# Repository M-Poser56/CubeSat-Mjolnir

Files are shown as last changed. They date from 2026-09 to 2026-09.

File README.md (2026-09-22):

# CubeSat-Mjolnir
Repository for the Mjolnir CubeSat personal project, tracking all code and design material.

The Mjolnir CubeSat is a 10cm by 10cm by 10cm (1U) microsatellite complete with an onboard flight computer, sensor telemetry, radio module, a camera module, custom onboard BMS, onboard attitude control via reaction wheels and custom motor control PCB.

There is also a fully custom groundstation consisting of a python backend and JS frontend, meant to interface with an Arduino Uno running a script to interface with a matching LoRa radio module to the CubeSat.

Had a blast making this, design doc covers everything and is worth a read!

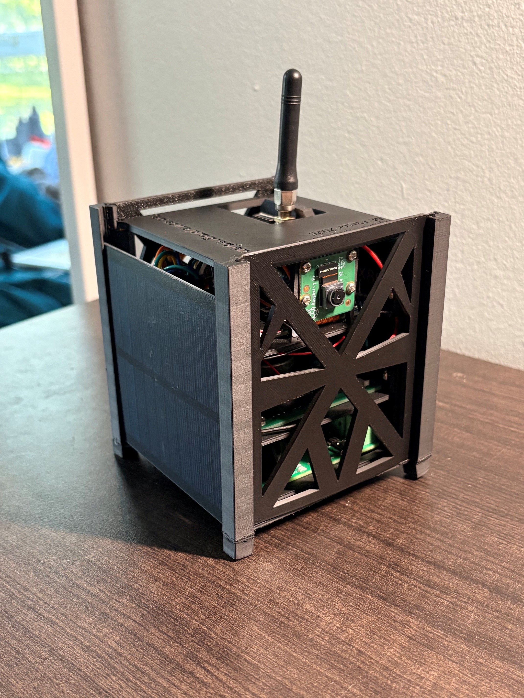
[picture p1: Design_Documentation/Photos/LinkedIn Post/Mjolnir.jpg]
Mjolnir CubeSat


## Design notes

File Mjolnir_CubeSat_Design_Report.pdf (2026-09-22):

# Mjolnir CubeSat Design & System Architecture Report

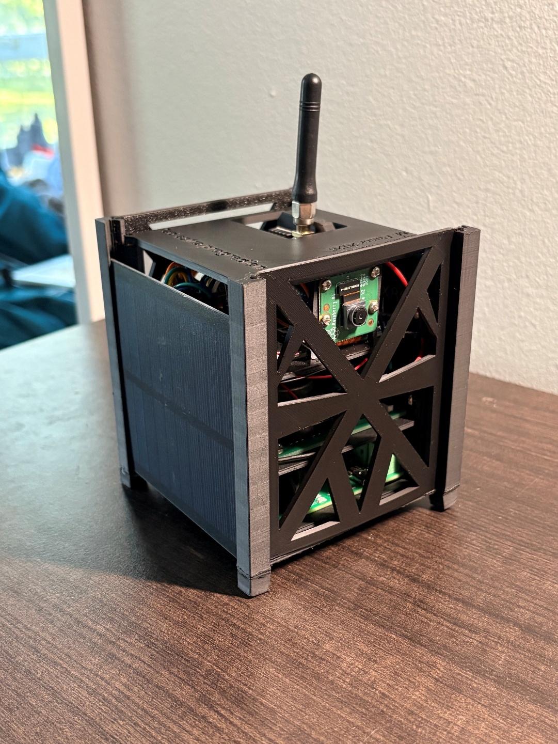
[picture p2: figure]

Matt Poser, Queen’s University Engineering Physics September 17th

, 2026

# Preamble/Abstract

The goal of this document is to notarize the design decisions, architecture, and detailed subsystems of the Mjolnir CubeSat personal project (similarly to my earlier M.A.E.S.T.R.O document) now that the Mk.I version is complete. This project was initially conceived when doing job market research and looking at the RocketLab Toronto engineering team, responsible for constructing reaction wheels and star tracker components for sale to the general space industry. Upon further research, I found out about student space projects, and specifically the CubeSat design standard used by industry engineers, hobbyists, and university students across the world. I set out to learn more and make my own, to learn about the relevant design challenges, subsystems and components commonly seen within the space industry and on operational satellites.
From a high level, the Mjolnir (Mk.I) CubeSat is a 1U design made from 3D printed PLA (fast prototyping), complete with an onboard Raspberry Pi Zero2W (flight computer), PiCamera V2, Adafruit LoRa radio module (915MHz), Adafruit BNO055 9 degree-of-freedom inertial measurement board, a custom made reaction wheel motor control PCB & reaction wheels, and a fully custom 5V output Lithium Ion (18650 cells) battery management system with a custom designed PCB. The CubeSat is specifically designed to communicate with a ‘ground station’ comprised of my laptop (running frontend display & backend software) paired with an Arduino Uno & accompanying Adafruit LoRa module which can receive onboard sensor telemetry, as well as send commands to change onboard configurations on the flight computer.
In its current state, the Mk.I is a simple prototype (and notably NOT spaceflight worthy), meant to act as a learning tool about PCB design, 3D modeling, software design, and relevant space applications. It works fully as intended, broadcasting down sensor telemetry packets and accepting commands from the ground station during active operation. Being a 1U design, there was not much room for scientific equipment or significant ‘launch payloads’, however if I ever were to attempt a 2U (or larger) footprint CubeSat I would attempt this, and possibly make it launch-worthy. I had an absolute blast with this project, and I am hoping to use it as a talking point in interviews and on job applications (if you’re a recruiter reading this, get in touch!). I set out on this project to learn, and to improve my skills in 3D modeling, software, and PCB design, and achieved all of those goals in full.
- Matt Poser, Sept. 17th 2026

## Table of Contents

Mjolnir CubeSat Design & | 1
System Architecture Report | 1
Preamble/Abstract | 2
Project Motivation, Background | 5
Initial LoRa Radio Test | 8
General System Architecture, Operation | 10
Mechanical Design, Tray System | 12
Tray I – BMS & Power Supply Board | 15
Tray II – Reaction Wheels | 20
Tray III – Flight Computer, IMU, Radio, Startracker | 24
Flight Computer Software | 27
Groundstation, Software & Hardware | 29
Final Assembly, Future Project Considerations | 30

Figure 1- Star Trackers, from the RocketLab Website: https://rocketlabcorp.com/space-
systems/satellite-components/star-trackers/ | 5
Figure 2- Reaction wheels, from the RocketLab website: https://rocketlabcorp.com/space-
systems/satellite-components/reaction-wheels/ | 6
Figure 3- 1U CubeSat footprint design standard, CubeSat official foundation | 7
Figure 4- Adafruit LoRa modules, selected to be used both onboard the CubeSat and on the
groundstation | 8
Figure 5- Soldering job of the two purchased Adafruit radio modules. Note the safety goggles on the
left, PPE is important! | 9
Figure 6- Photo of the 'test bench' setup for the LoRa radio hardware test. See the 'groundstation'
Arduino on the left hand side, and the Pi 4B on the right hand side | 9
Figure 7- Note the shell output from the Pi side of the ping pong script. Messages were actively being exchanged back and forth between the two radios, on regular intervals, for sustained periods
of time | 10
Figure 8- Initial CubeSat tower design. Struts and flat base follow 1U design standard | 12
Figure 9- Model for CubeSat frame with risers and machined holes for heat set inserts | 13
Figure 10- Heat set inserts installed in the Mk.I outer frame | 13
Figure 11- CubeSat outer frame with teal tray template prints installed at various heights within the CubeSat. These were used to confirm design dimension, as well as verify fit and the ideas behind
the tiered system | 14
Figure 12- used a Dremel tool to file down the slots of the CubeSat in an attempt to fit the solar panels. The height dimension was correct, however in the end the frame required a redesign of the
slots in order to accommodate the solar panels as wall units | 14

Figure 13- CubeSat Lid, the last component to be designed for the structural system and the

Figure 23- Motor control PCB circuit, using two of the Texas Instruments L293DNE ICs. Two dual H bridges meant 4 total motors could be controlled, but I only required 3 axes of control, thus one

Figure 26- Motor control PCB soldered, and fastened to reaction wheel tray along with reaction wheel motors. Flywheels would be printed and assembled later, along with all wiring connections

Figure 27- basic layout of Adafruit BNO055 IMU board, Mjolnir flight computer, LoRa radio module

Figure 32- IMU sub-script, interfaces with Adafruit IMU to obtain attitude and temperature readings, publishes sensor packet to an mqtt topic read by the main LoRa script, which is then sent down to

Figure 34- Arduino Uno groundstation module. Yellow serial cable plugs into the USB port of my

Figure 35- Initial electronics test. See the mess of wires coming out of the flight computer, the 3D printed flywheels on the reaction wheel motor controller, and the bench power supply being used

# Project Motivation, Background

As I mentioned in the executive summary portion of this document, I had initially been looking into jobs for various internship roles while at Queen’s & on my internship at OPG. I had found a posting for RocketLab’s engineering team which worked on making reaction wheels and star trackers for satellite applications, and at the time I had yet to learn what either of these were. Intrigued, I did some research and found documentation both star trackers and reaction wheels, as well as their use in spacecraft design. For the un-initiated, a star tracker is a special kind of camera which takes photos of the stars while a spacecraft is in orbit or traveling through space. The star tracker then maps this photo to a known star map (360* panoramic view of the night sky), using specially designed software to determine the vector direction that the camera (and thus spacecraft) is pointing in, as well as the angular orientation. This is an important task for navigation of spacecraft, as well as calibrating the onboard orientation sensors to a known source.

Figure 1- Star Trackers, from the RocketLab Website: https://rocketlabcorp.com/space-systems/satellite-components/star-trackers/ (https://rocketlabcorp.com/space-systems/satellite-components/star-trackers/)
The next component I had yet to learn about was reaction wheels. Once your spacecraft has its exact angular orientation in space determined (combination of star tracker & onboard sensors), the operators back on earth (or onboard) may wish to change the angular orientation. This could be to face solar panels towards the sun, change attitude (angular orientation) to face a celestial body/source for imaging, or other reasons. You could accomplish this with thrusters, however reaction wheels also achieve the task of changing angular orientation in space, via the conservation of angular momentum. Let’s frame the problem as the following. Your spacecraft has a total moment of inertia Ispacecraft. If we define the total angular momentum of the spacecraft as Lspacecraft, we can represent it with the following equation:
Lspacecraft = Ispacecraft ∗ ω | (1)
Where ω is the angular momentum of the entire spacecraft body, with all of its components. We will say, that buy and large after launch, our spacecraft is rotating a minimal amount in a nearby observer’s frame of reference. Thus, Lspacecraftis equal to 0. Since we know that Ispacecraft is nonzero (our spacecraft has mass), then we know that our spacecraft’s total angular momentum (ω) must be 0. Thus, our equation (1) becomes:

0 = Ispacecraft ∗ ω
Now, what we will do is break up the above equation into a combination of simple parts. We can say that the total angular momentum of our spacecraft, is equal to the sum of the angular momentum of smaller components within the spacecraft, along with the spacecraft’s outer body. For now, we will formalize this along one arbitrary axis, saying we have a single internal component which can take angular momentum ω2. Our equation (1) then becomes:
0 = Ibody ∗ ω1 + Iflywℎeel ∗ ω2 | (2)
We can see, that for the above equation to remain valid, either ω2 = ω2 = 0, or they must take opposite signs and cancel one another out, as we specify that both Ibody and Iflywℎeel are positive real tensors (though, in this single axis approximation we can think of them as scalar values). What this means is that if there is no external addition of angular momentum to the entire spacecraft assembly, you can still induce angular momentum in the external spacecraft body by making an internal component spin (have nonzero angular momentum). This in turn allows the crew to rotate the spacecraft, altering its attitude in a known and controlled way. This internal rotating component used to change spacecraft attitude, is the reaction wheel. Perhaps an easier (and less long winded) way to think about this is to say that if our spacecraft starts at rest (no angular momentum), and a wheel inside starts spinning in one direction, the whole spacecraft (external body) must rotate in the other direction to conserve angular momentum, which remains zero for the entire spacecraft.

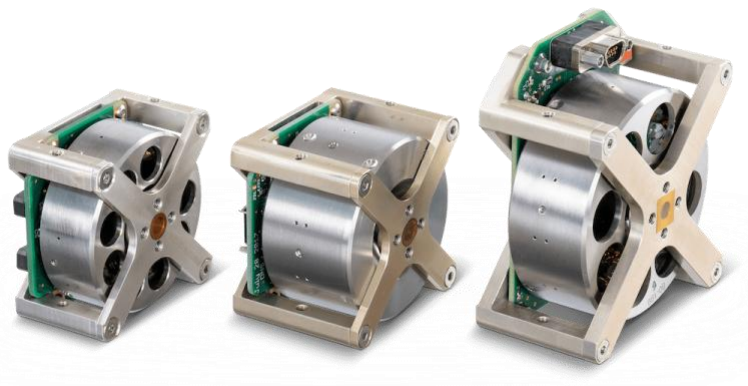
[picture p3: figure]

Figure 2- Reaction wheels, from the RocketLab website: https://rocketlabcorp.com/space-systems/satellite-components/reaction-wheels/ (https://rocketlabcorp.com/space-systems/satellite-components/reaction-wheels/)

Having learned about all of this, I was now curious about the industry of satellite design. I also found several resources pointing to CubeSats; used for both real-world space deployments and by university teams. CubeSats (as I have come to know) are satellites which follow a specific design standard, limiting their total physical footprint to multiples of 10cm/10cm/10cm. A singular 1000cm³ satellite is referred to as a 1U (1 unit) CubeSat, and different multiples of this are referred to aptly as 2U, 3U, so on and so forth up to 12U satellites. Shown below is a photo of the official 1U design standard from the CubeSat foundation:

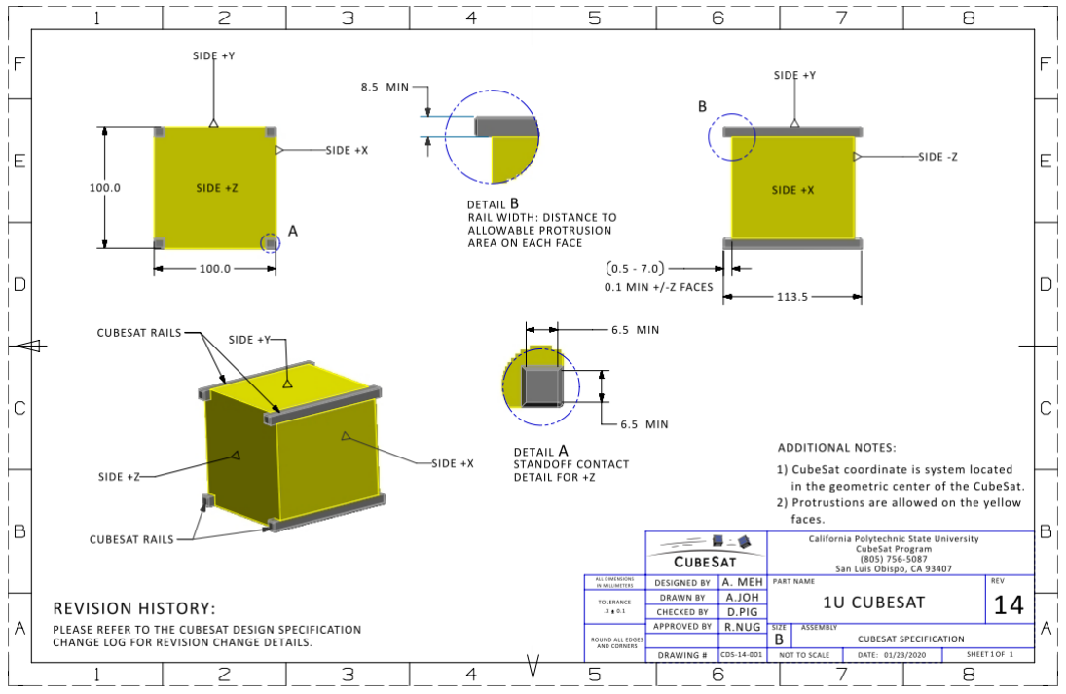
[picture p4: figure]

Figure 3- 1U CubeSat footprint design standard, CubeSat official foundation
The best thing about CubeSats for both students and professionals is that they were invented to circumvent the costs of launching satellites into orbit. Before CubeSats, launching a satellite meant that an organization would spend potentially millions of dollars building and launching a behemoth sized instrument on a rocket. This made the practice of satellite design and operation inaccessible at an entry level. With the much smaller footprint CubeSats, engineers and physicists can collaborate to design satellites for scientific purposes on a smaller scale for reduced cost and can afford to launch via rideshare. Instead of a company paying 6 (or more) figures to use a dedicated launch vehicle to put only their satellite into orbit, rideshares via companies like NASA or SpaceX will carry and launch hundreds of these CubeSats at a time on a single launch vehicle, allowing participating parties to collectively pay for the launch vehicle operation & reduce the cost of putting their experiment in space.
By this point I was thoroughly intrigued, and wanted to take on the project of building my own CubeSat (despite not being able to afford the roughly $50,000 - $80,000 rideshare launch bill). I began project planning for a 1U CubeSat of my own, and made a laundry list of technical skills I hoped to practice and improve upon during this project. In late April 2026, I kicked off the project and began documentation.

# Initial LoRa Radio Test

Similarly to my M.A.E.S.T.R.O desktop robotic arm project (also on my GitHub, check it out!), this project too relied on a core concept/component, and without proper operation/functionality the project would not be able to be attempted. For this project, that concept was radio communication via an I/O module, in this case a LoRa radio module. LoRa radio simply stands for long range radio, and is a special standard of radio communication which is used to send signals & information from node to node. LoRa radios are considered useful for simple & low power radio applications (with surprisingly good range), and can be configured in networks and meshes for message relaying. In this application, my understanding was that my CubeSat (Mjolnir, Mk.I) would require an onboard radio module which could both send and receive messages/packets. This onboard radio would need to communicate with a groundstation of some kind, built to receive onboard information from the CubeSat and also send commands to the onboard flight computer. I planned outright to use a Raspberry Pi Zero 2W running headless Linux as my flight computer, making use of the GPIO pins and python as a powerful I/O base for onboard sensors & modules. Using this as initial inspiration, I settled on the Adafruit RFM9x 915MHx LoRa modules. These modules were relatively low power and used GPIO based SPI (serial peripheral interface) communication protocol to operate. Further, there was a supported software library for both the python operated GPIO on the raspberry Pi (Adafruit custom), as well as the Arduino microcontroller family (radiohead library). The choice of an Arduino (Uno) is discussed later in the groundstation section of the report, but ultimately the flight computer radio module was to be operated by the onboard Raspberry Pi Zero 2W flight computer & python, while the groundstation would use the Uno & radiohead.

Figure 4- Adafruit LoRa modules, selected to be used both onboard the CubeSat and on the groundstation
When purchased and delivered, the antennae had to be soldered onto both boards, using a special SMD (surface mounted device) for antenna connection. This was my first experience doing non through-hole soldering, and took a lot of patience to complete. Eventually, I was able to finish the job & assemble both radio boards for use:

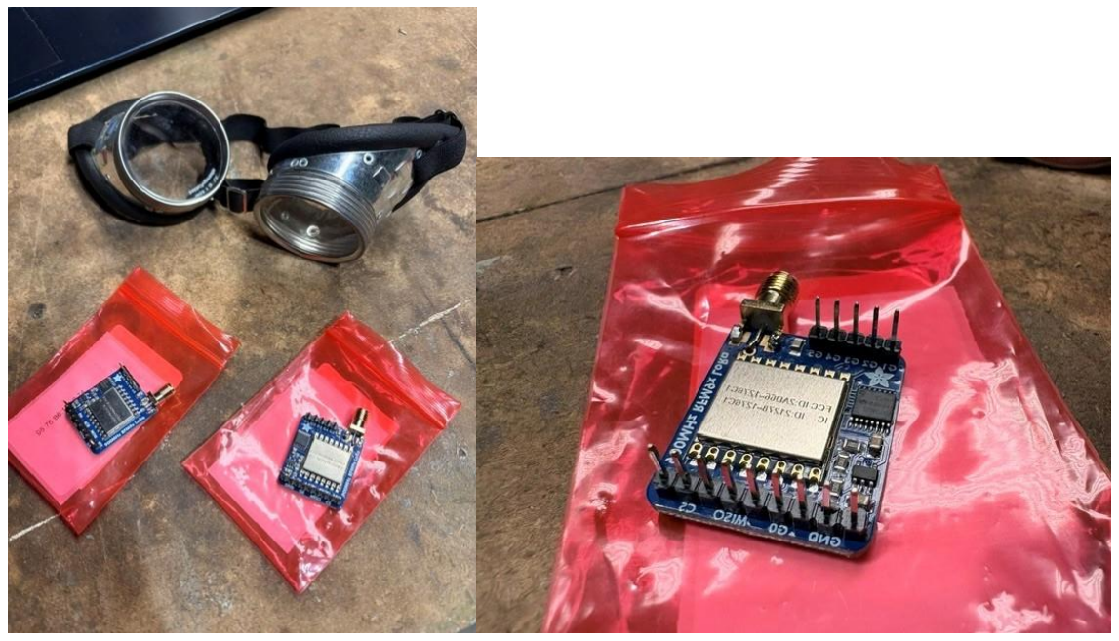
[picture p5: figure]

Figure 5- Soldering job of the two purchased Adafruit radio modules. Note the safety goggles on the left, PPE is important!
Once finished with the soldering job, I wrote up a quick ‘ping pong’ script for both the Arduino, and a Raspberry Pi 4B (nice to develop on a desktop environment, while still using python/GPIO the same way as the Zero 2W would), where one radio would send out a ping, and wait for the other radio to respond with a ‘pong’ return message. Once wired up on both the Pi 4B and Arduino Uno, the test ran successfully verifying that these LoRa modules could be used, as well as the fact that my soldering job held up (which, in and of itself, was no small act of divine intervention).

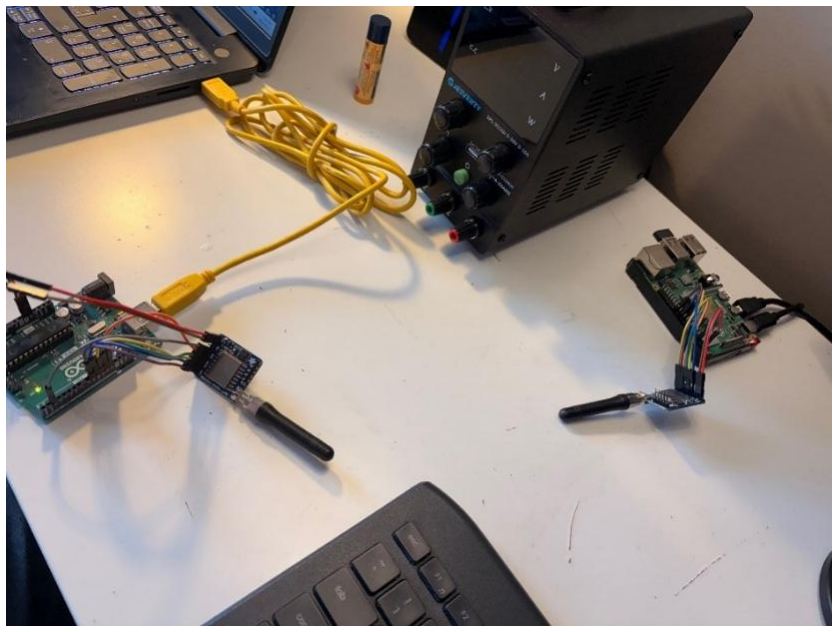
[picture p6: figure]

Figure 6- Photo of the 'test bench' setup for the LoRa radio hardware test. See the 'groundstation' Arduino on the left hand side, and the Pi 4B on the right hand side

Figure 7- Note the shell output from the Pi side of the ping pong script. Messages were actively being exchanged back and forth between the two radios, on regular intervals, for sustained periods of time
With this successful test, the project could now be fully attempted. If the radio modules did not end up working, then alternative options would have been explored until a viable choice was found for the project. However, this easy use case meant that I could proceed with a general architecture of CubeSat and groundstation in mind.

# General System Architecture, Operation

The general architecture of the CubeSat project is that of an uplink/downlink communication scheme. Under regular operation, I wanted the CubeSat to publish regular packets down to the groundstation, alongside other system/operational information as needed. The groundstation would display this information to the operator via a nice frontend display panel, which doubled as an interactive and easy to use control station to send commands to the CubeSat. Onboard the CubeSat, I would need to mesh onboard instruments such as the LoRa radio module, reaction wheels, star tracker camera, and inertial measurement sensor (angular orientation/attitude measurements, temperature) with the Pi Zero2W flight computer. The flight computer would dually need to send packets down in a known protocol to be processed by the ground station, as well as receive and process known commands coming from the ground station to perform preset flight computer operations. Below is the block diagram format of both the groundstation & CubeSat high level architecture:

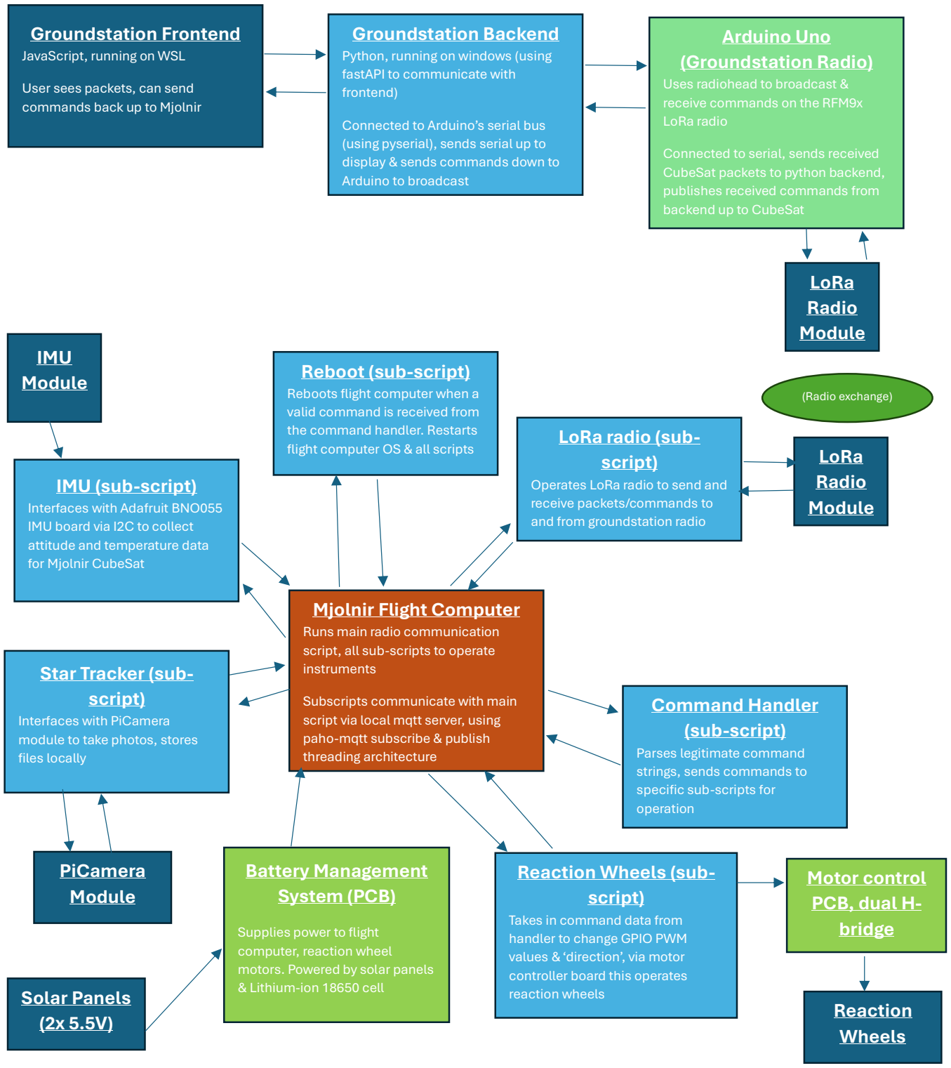
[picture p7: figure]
Groundstation Frontend JavaScript, running on WSL; User sees packets, can send commands back up to Mjolnir; Groundstation Backend Python, running on windows (using fastAPI to communicate with frontend); Connected to Arduino’s serial bus (using pyserial), sends serial up to display & sends commands down to Arduino to broadcast; Arduino Uno (Groundstation Radio) Uses radiohead to broadcast & receive commands on the RFM9x LoRa radio; Connected to serial, sends received CubeSat packets to python backend, publishes received commands from backend up to CubeSat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

# Mechanical Design, Tray System

The work for this project began with the design of the physical enclosure to hold all components within the CubeSat. At this point, I had brainstormed general components which would be included in the CubeSat’s design, however I did not have a concrete idea as to how I should mount and fasten them when inside the frame. I had the idea that the physical enclosure should follow a ‘tower’ design, with mounting points along vertical struts for components to be screwed in. I designed the tower to dimension with the 1U standard, and was able to produce the following initial 3D model:

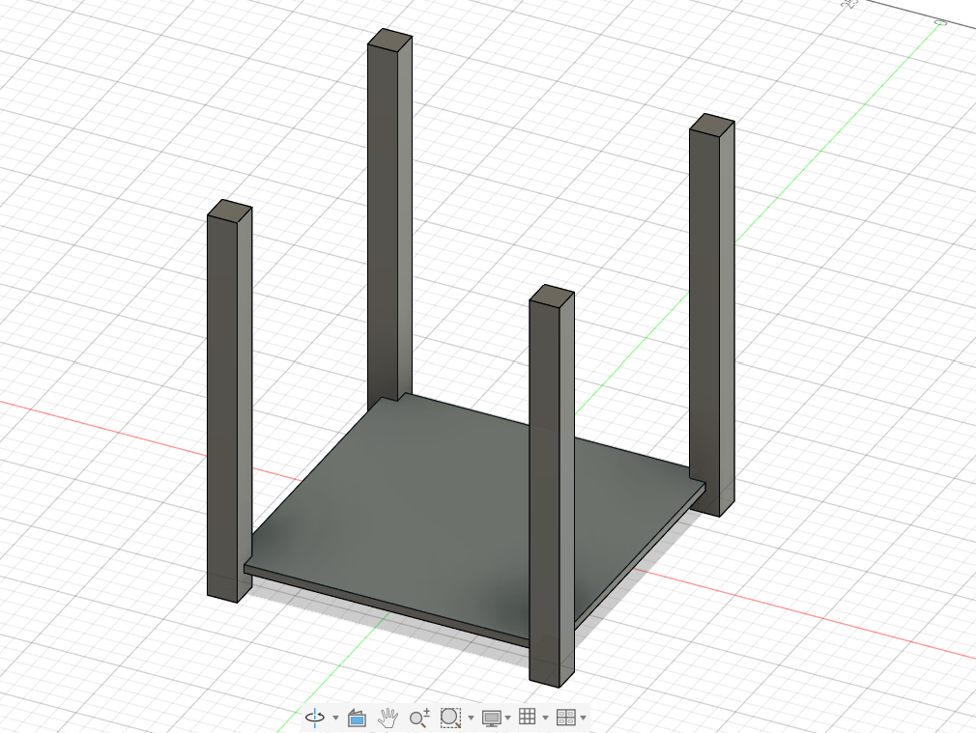
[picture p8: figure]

Figure 8- Initial CubeSat tower design. Struts and flat base follow 1U design standard
To mount objects to these towers, I designed in further risers which would hold heat set inserts. Planning on 3D printing these prototypes for this project, heat set inserts allowed me to have a way to use metric fasteners (M3 for this project) to mount all of my components to the frame. Heat set inserts are used by machining a pre-drilled hole in a 3D print, and with a soldering iron pressing in the inserts (heat melts away the plastic around them) to hold them securely in place. This provides a secure threaded anchor for M3 screws. Photos are shown below of the frame’s 3D model, and the heat set inserts assembled into the mounting points.

Figure 9- Model for CubeSat frame with risers and machined holes for heat set inserts

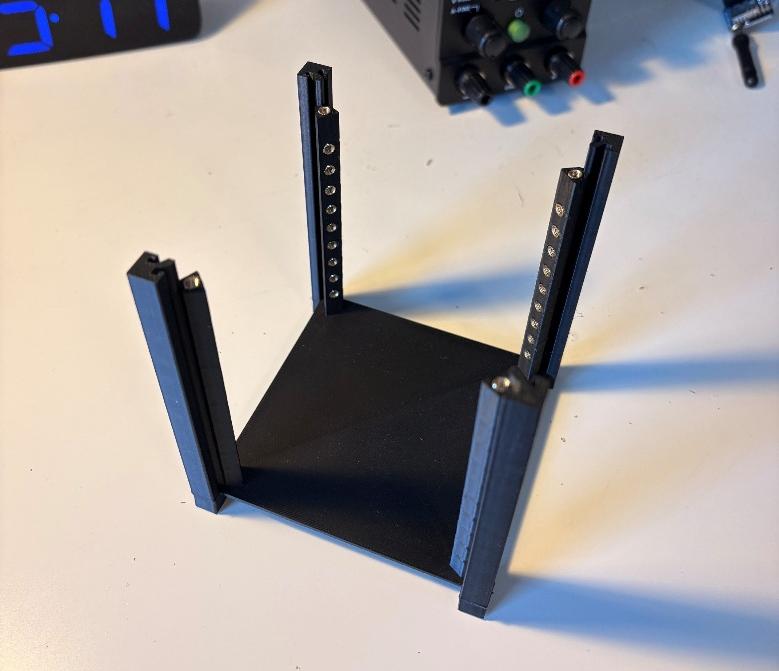
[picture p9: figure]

Figure 10- Heat set inserts installed in the Mk.I outer frame
In the designing of these towers, I also elected to implement slots for future installations of walls, as at the moment I did not know what they would look like exactly. Zooming in on the top of the tower in figure 10 shows this, there are acceptor slots which would allow a general wall design to be slid in from the top and held in place by a lid.

After the installation of the heat set inserts on the first frame, I had the idea of implementing a tiered ‘tray’ design. If I had a general footprint for a platform which could be fastened into the heat set inserts via M3 screw, I could start with the same template sketch for all trays which I wanted to install in the CubeSat. This also made it a modular design, meaning in theory trays could be swapped in and out and installed in different configurations. Shown below are some photos taken later in the CubeSat’s design phase, including the teal-colored tray template prints fastened to the frame design, as well as the purchased solar panels inserted into machined slots in the frame (solar panels were big enough to act as the CubeSat walls).

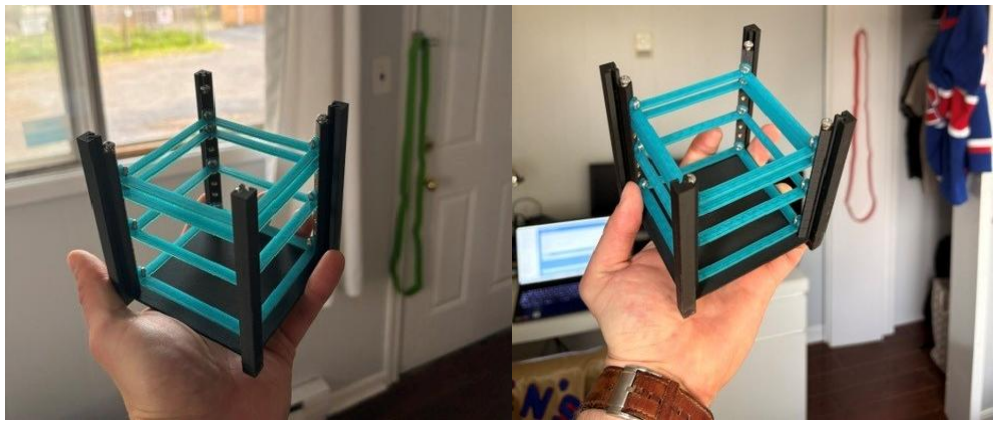
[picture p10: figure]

Figure 11- CubeSat outer frame with teal tray template prints installed at various heights within the CubeSat. These were used to confirm design dimension, as well as verify fit and the ideas behind the tiered system

Figure 12- used a Dremel tool to file down the slots of the CubeSat in an attempt to fit the solar panels. The height dimension was correct, however in the end the frame required a redesign of the slots in order to accommodate the solar panels as wall units

The structural subsystem was the least intensive part of this project, and was also the first component to undergo design work (the frame), as well as the last (the lid). A photo of the final CubeSat Lid 3D model is shown below, this lid screws into the top of the frame towers to cap off the top tray (containing flight computer, IMU, radio, and camera module).

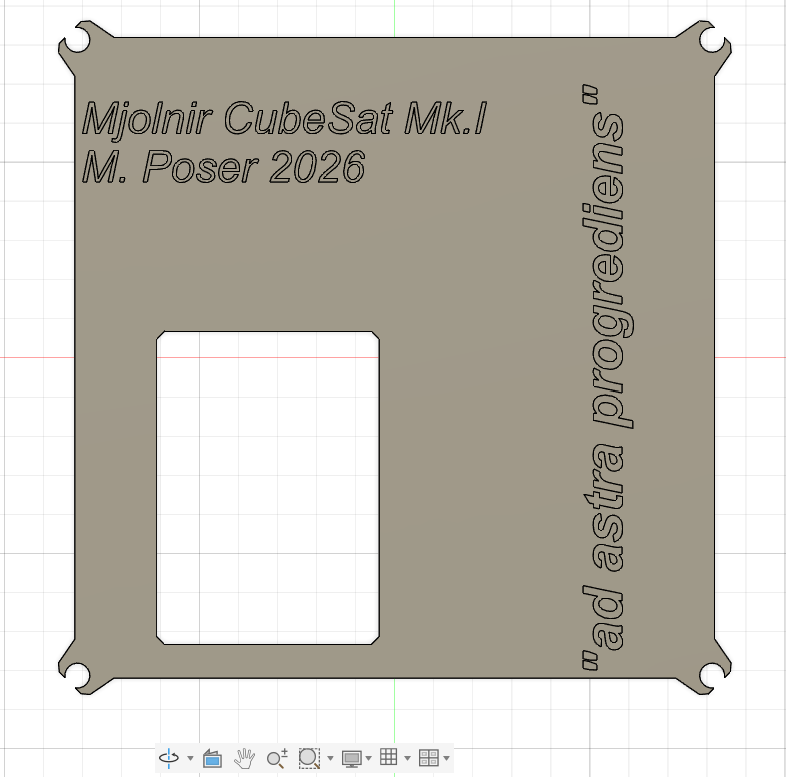
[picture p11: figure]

Figure 13- CubeSat Lid, the last component to be designed for the structural system and the CubeSat as a whole. Latin saying roughly translates to "forward unto the stars"

# Tray I – BMS & Power Supply Board

The BMS (battery management system) for this CubeSat was an immense amount of work, and presented a very large learning curve for me in terms of PCB design. When talking about this project with one of the engineers on my team at OPG, he convinced me to try and make a custom made BMS, as opposed to purchasing a basic one off the market (my initial inclination). He recommended that I begin with chip design, and lay out a couple of key functionalities for the board:
1. Board must be powered by an 18650 Lithium ion cell, 3.7V nominal
2. Board must have power path management, take in power from both the battery source and the solar panel charging units
3. Board must have aforementioned 18650 cell protection (undervoltage, overvoltage, overcurrent, temperature)
4. Board must take the varying output voltage from the battery/solar panels and boost it up to a consistent 5V
For these basic specifications, I selected the TI-BQ24074 charging chip, TI-BQ29704 battery protection chip, and the TPS61023 boost converter chip for power output. I essentially followed the exact sample designs from the Texas Instruments design manuals for each chip, stringing each chip together in the schematic to complete the design. I also elected to include a USB-C power input on my BMS PCB, considering that much of the testing I would be conducting would occur at my desk, and I had a high current desk power supply on hand for quick battery charging. Screenshots of each major component/circuit are shown below, with KiCAD comments outlining the specific function of each circuit on the board:

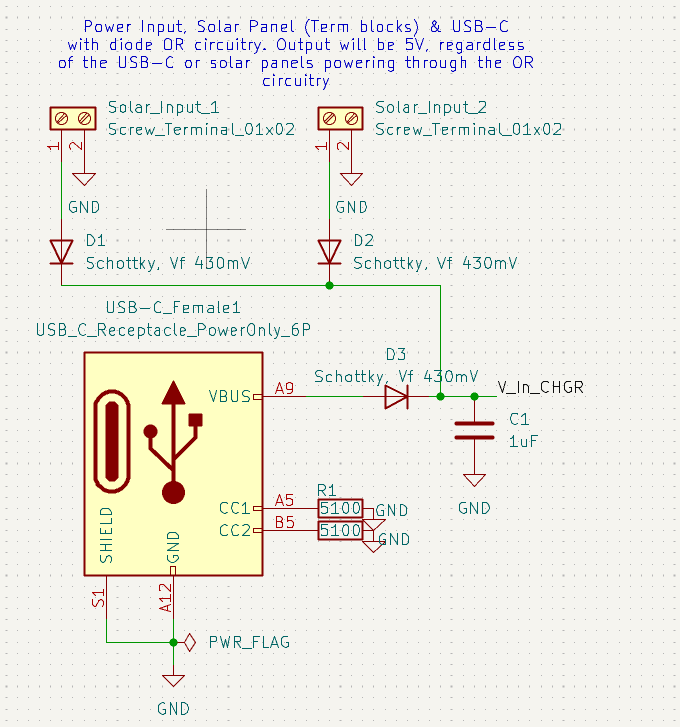
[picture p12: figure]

Figure 14- Power input circuit, with diode OR circuit to feed charging chip

Figure 15- Power path charging chip circuit

Figure 16- Battery protection circuit

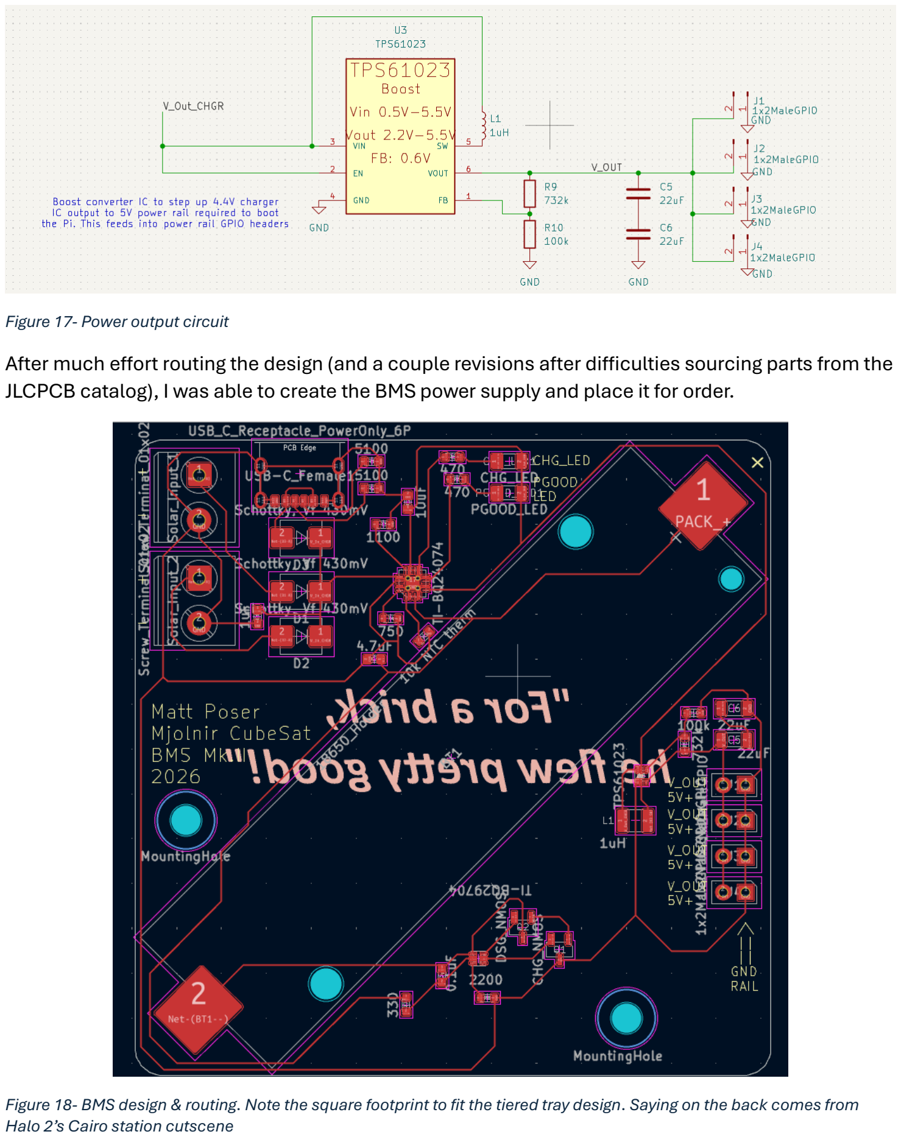
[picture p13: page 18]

Figure 17- Power output circuit
After much effort routing the design (and a couple revisions after difficulties sourcing parts from the JLCPCB catalog), I was able to create the BMS power supply and place it for order.

Figure 18- BMS design & routing. Note the square footprint to fit the tiered tray design. Saying on the back comes from Halo 2’s Cairo station cutscene

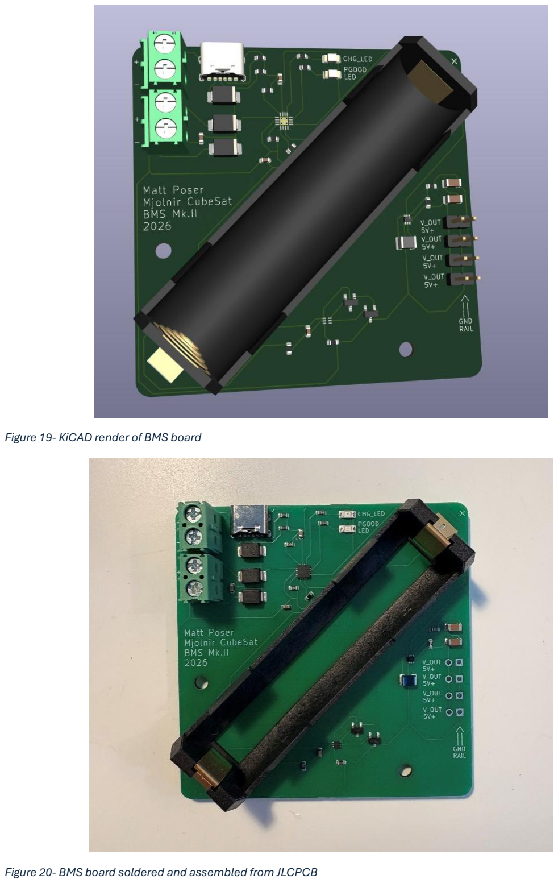
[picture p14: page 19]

Figure 19- KiCAD render of BMS board

Figure 20- BMS board soldered and assembled from JLCPCB

Figure 21- BMS Power test
By far, out of all aspects of this CubeSat project, I struggled the most with the PCB design for the BMS. It was amazing to see it all come together after weeks and weeks of effort, and to finally see the green light turn on during testing was a really awesome sight. This struggling with KiCAD and JLCPCB also prepared me greatly for the much easier reaction wheel motor control PCB design, so much so that I was able to knock out the motor control PCB in one sitting, and have the order placed with JLCPCB within one afternoon.

# Tray II – Reaction Wheels

As I discussed in the introductory section of this report, one of the main inspirations for this project was the reaction wheel subsystems seen on satellites and other spacecraft. My 1D approximation of the conservation of angular momentum problem would now be applied along three axes, to control pitch, roll, and yaw of the CubeSat. The first part of this component which needed to be selected was the reaction wheel motors themselves. I was operating under some serious engineering constraints, left with only a 5V power supply and limited space for 3 flywheel motors my options were limited. I settled with a cheap option from amazon, a basic cylindrical 5V DC motor with high enough rpm (roughly 1000) to spin the reaction wheels fast, while maintaining a small footprint within the constrained space of my 1U design.

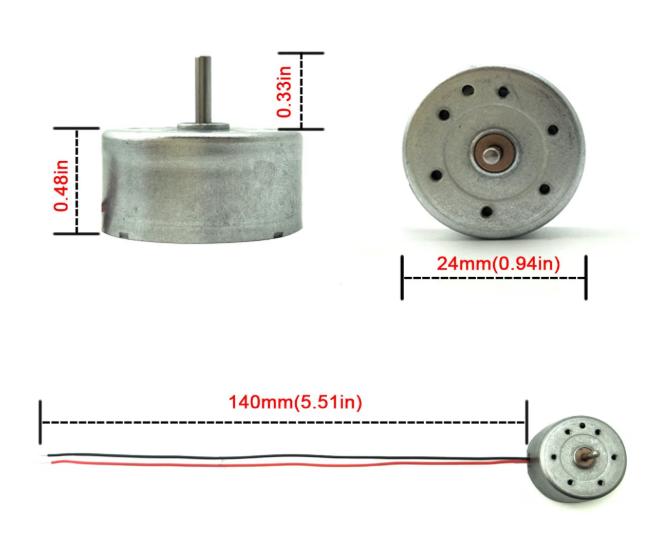
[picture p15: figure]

Figure 22- 5V DC motors off amazon
Luckily, I had experience using H-bridge motor control chips before, from my time spent tinkering with an Arduino starter kit in my first year at Queen’s. In the starter kit, there was a Texas instruments L293DNE dual H-bridge motor IC, with built in flyback diodes (designed specifically for use with DC motors). This chip operates by using a series of input pins, to control the motor using low-current logic PWM pins (for speed) and low current digital pins (for direction). It has a separate power bus for the motors, so your logic pins are never electrically connected to your motor and thus would not cause damage to the controller (in this case, the logic pins coming directly from the Mjolnir’s flight computer). I built a quick test circuit to ensure that the L293DNE was 3.3V logic compatible (Raspberry Pi has 3.3V GPIO I/O & PWM) and began work designing the motor control PCB.

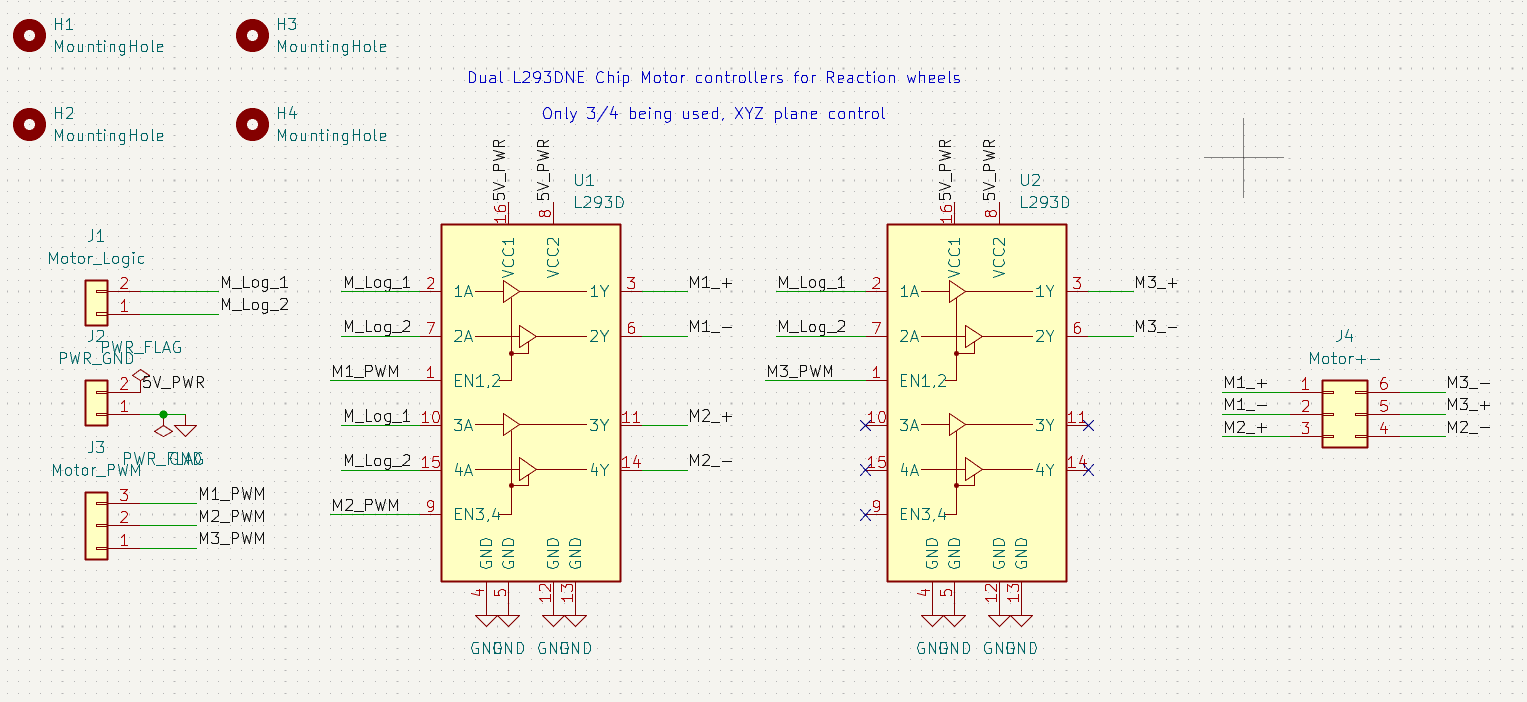
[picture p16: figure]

Figure 23- Motor control PCB circuit, using two of the Texas Instruments L293DNE ICs. Two dual H bridges meant 4 total motors could be controlled, but I only required 3 axes of control, thus one was left empty

The above circuit takes in two digital logic pins (0,1 or 1,0) which determines the direction of all motors in the circuit (clockwise versus counterclockwise). The 3 PWM pins on the above circuit receive 3.3V PWM signals of varying duty cycles (set to 490Hz) from the Mjolnir flight computer, and are used to control motor speed on each of the pitch/roll/yaw motors. The choice of 490Hz was made to mirror my past (and well tested) use of these TI chips with an Arduino Uno’s PWM outputs, which are set to 490Hz for standard pins. Under normal operation the Mjolnir flight computer would be receiving commands from the groundstation to set the states (direction, speed) of the pitch/roll/yaw motors, which would subsequently be outputted to these pins on the motor control board to interface with the reaction wheel motors. The circuit was traced out for the above PCB, and all the soldering for these boards was completed by me as opposed to the BMS which was assembled by JLCPCB.

Figure 24- motor control traces. Also experimented with more PCB layers for drawing traces

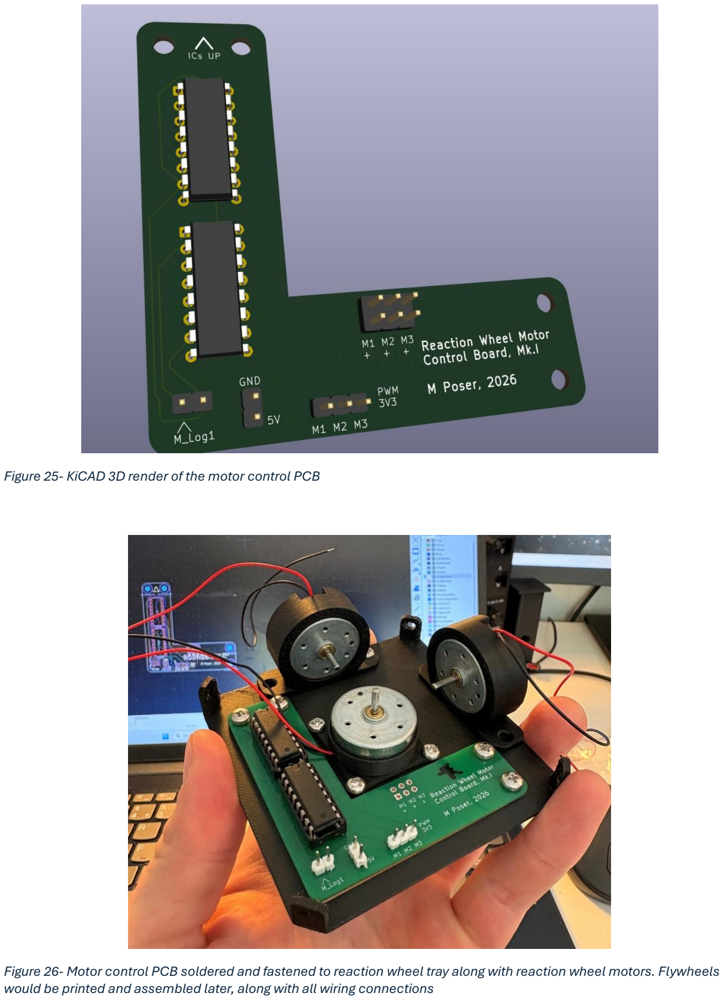
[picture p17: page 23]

Figure 25- KiCAD 3D render of the motor control PCB

Figure 26- Motor control PCB soldered and fastened to reaction wheel tray along with reaction wheel motors. Flywheels would be printed and assembled later, along with all wiring connections

Contrary to the BMS PCB design, I had a lot of fun making this motor control PCB, and of all the trays on the CubeSat this one is by far the cleanest and the nicest organized. This board underwent basic testing before final soldering and assembly, and performed admirably. The 5V motors also (surprisingly so) pulled much less current than expected at full draw, meaning there was not much strain on the BMS power supply even while running alongside the flight computer & radio module in active operation.

# Tray III – Flight Computer, IMU, Radio, Startracker

This final tray on the CubeSat contained much of the finer components in the design, and can be seen as the ‘brain’ of the Mjolnir CubeSat. This final tray would contain the central flight computer, radio module, inertial measurement unit, and (after iteration) the camera module. As well, for the sake of the radio antenna sticking out of the top of the CubeSat, this tray would be mounted at the top. Before completing any major wiring, a basic layout of the top tray was printed and assembled, to assess space constraints.

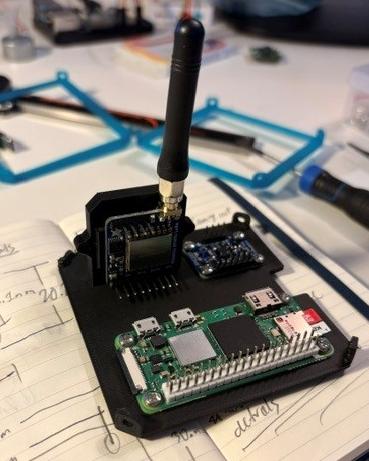
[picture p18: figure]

Figure 27- basic layout of Adafruit BNO055 IMU board, Mjolnir flight computer, LoRa radio module

Figure 28- top tray assembled on frame with BMS

Figure 29- Top tray assembled on frame with BMS (2)

Once this basic orientation was figured out, the next component to be added was the PiCamera module for the star tracker. Based on the length of the available camera cable with the module, this also was chosen to be mounted and included in this top tray. Shown below is the 3D model of the top tray, with the outwards facing mount for the PiCamera module. It was noted here that the wall design on this side of the CubeSat would need to have a hole/opening in its face to accommodate the camera’s field of view facing outwards.

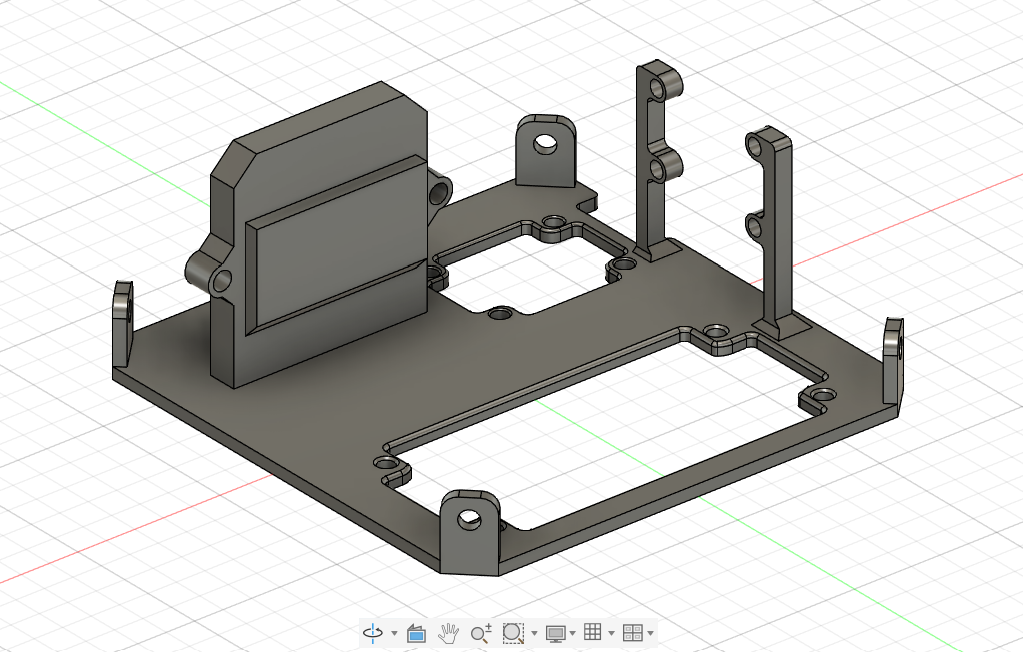
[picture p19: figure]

Figure 30- Top tray with PiCamera mounting arms extruded from the base of the tray
It is pertinent to note that this tray was impossibly hard to print, the small thin arm extrusions for the PiCamera were very finnicky, and often broke either in printing or in assembly afterwards when fastening the camera on. Eventually, all components were mounted on the tray, and I began initial testing of the flight computer software. Shown below is a photo of the top tray with some of its initial wiring completed (IMU & reaction wheel controls still disconnected from flight computer).

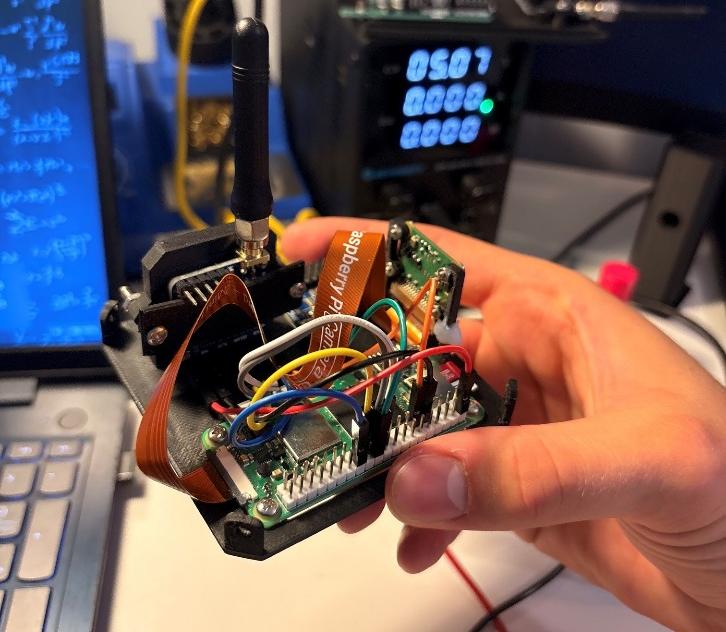
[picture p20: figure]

Figure 31- top tray assembled with PiCamera and LoRa radio module

# Flight Computer Software

The software on the flight computer was very fun to write, and served as the culmination of the project (alongside the software & hardware of the groundstation, next section). As shown in the above general architecture section, the software on the flight computer is all written in python as a series of sub-scripts which communicate with one another using mqtt architecture (mqtt-paho python library). This mqtt architecture was something I had the opportunity to learn about while on my co-op placement at OPG, and is definitely one of the cooler items in my software ‘bag of tricks’. Each script revolves around the same general architecture:
1. Check for a message on an incoming mqtt topic which the script is subscribed to
2. Do something with that packet/message
3. Once the function has been run either publish a message to another topic or report success
4. Continue loop
While unfortunately I do not have the page count in this report to explain the architecture of mqtt at length, the long and short of it is that it is a way for different python scripts running completely separately from one another to exchange information in an asynchronous fashion using built in functions in the paho-mqtt package. The flight computer sets up a local mqtt server/broker, and paho-mqtt allows scripts to publish and read packages from specific ‘topics’ (like directories) within this local server in a totally asynchronous fashion. What this looks like for the flight computer is that I can have a radio script running which receives IMU (inertial measurement unit) data via a separate script interfacing with my Adafruit IMU and publishing the sensor packets to a specific IMU/PACKET topic. Meanwhile, that same script can publish command data received from its radio to a COMMAND/ topic, which is then received by the command handler script running on a separate python instance. The flow of this controlled madness is outlined in the general architecture section’s block diagram, and with some reading of the code on the GitHub can be well understood. I tried to write the flight computer code with minimal usage of AI, and thus in some places it looks clunky. While it can be improved, I am happy because it is original code which runs without error. Shown below is a snippet of code, the IMU controller script which publishes IMU data to a topic read by the main LoRa radio control script.

Figure 32- IMU sub-script, interfaces with Adafruit IMU to obtain attitude and temperature readings, publishes sensor packet to an mqtt topic read by the main LoRa script, which is then sent down to the groundstation as a sensor packet

# Groundstation, Software & Hardware

Unlike the software written for the flight computer, I had a (relative) distaste for frontend design, and largely used AI to ‘vibecode’ this frontend portion of the project. As I mentioned earlier in this report, what I hoped was that the groundstation would be like an operator’s interface; allowing for the fast visualization of the sensor telemetry coming from the CubeSat, as well as providing the operator with a command panel and preset commands to broadcast to the CubeSat to perform onboard functions. The final command panel frontend is shown below, and the feature list discussed afterwards:

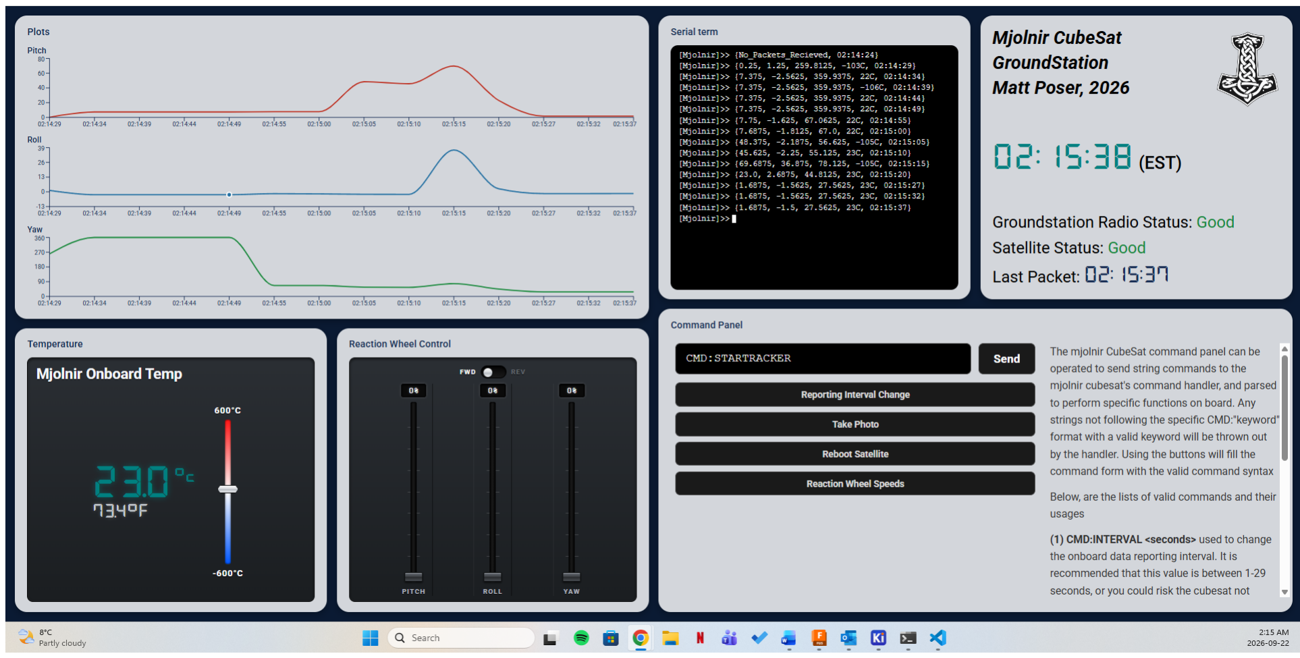
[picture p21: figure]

Figure 33- Mjolnir CubeSat groundstation operator panel, designed fully in JavaScript
As mentioned, the feature list is shown below:
1. Live serial terminal, to display packets exactly as they arrive from the CubeSat
2. Live attitude plots, pitch/roll/yaw angle values plotted against timestamp (EST)
3. Clock and status panel, status messages change if backend loses contact with radio, or if the CubeSat has not published a packet to the groundstation in an exceedingly long time (also displays last packet timestamp)
4. Onboard temperature display, temperature included in the CubeSat telemetry packet
5. Reaction wheel control sliders, control the PWM value and direction for the pitch, roll, yaw reaction wheels
6. Command panel, with guides on proper usage (command handler on the CubeSat just throws out bad commands). There are built in commands to:

a. Change the reporting interval of onboard sensor telemetry packets being sent from the CubeSat
b. Take a photo using the CubeSat’s onboard camera module
c. Reboot the Mjolnir flight computer
d. Control/change the reaction wheel speeds (using slider to set values & direction) This frontend (again, following the general architecture block diagram) sends command strings and receives sensor packets via a python backend (running on my laptop’s native Windows OS). This python backend uses fastAPI to interface and exchange these packets with the JavaScript frontend and uses the pyserial module to send/receive these same packets down to the low-level Arduino which is connected to the groundstation radio module. The Arduino code is nothing fancy, but I did take the time to write it without the use of AI. The Arduino/radio essentially waits for packets to arrive from the CubeSat, and if it receives any then it writes that command packet to the serial bus (thus received by the python backend). If the Arduino reads its serial register to be full (python backend has published a command to the serial bus, to be sent to the CubeSat), then the Arduino reads the contents of its serial register into a string object and sends it up to the CubeSat. Shown below is a photo of the Arduino/LoRa radio groundstation module.

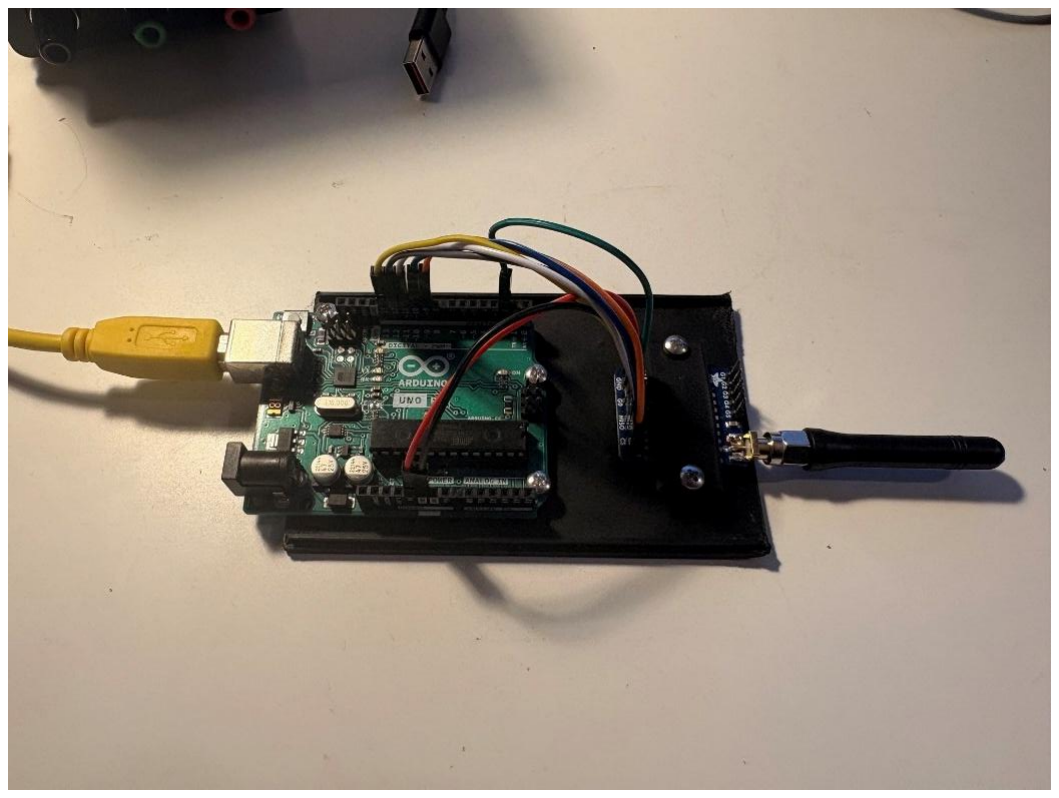
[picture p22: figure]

Figure 34- Arduino Uno groundstation module. Yellow serial cable plugs into the USB port of my laptop, to interface with python backend

# Final Assembly, Future Project Considerations

With the groundstation completed and all the trays built and tested, it came time to run the entire system in tandem and take readings with the groundstation. Shown below is a photo of the unassembled first electronics test, which involved making all electrical connections between modules and starting up all the onboard sub-scripts.

Figure 35- Initial electronics test. See the mess of wires coming out of the flight computer, the 3D printed flywheels on the reaction wheel motor controller, and the bench power supply being used to conserve battery (in lieu of)
This first electronics test ran with surprisingly minimal bugs, and was a large success. This test involved turning on 6/6 sub-scripts (LoRa radio, IMU, command handler, camera, reboot, reaction wheels) and testing all the software, as well as testing the performance of the groundstation sending/receiving commands. For the perceptive reader, you may see that the temperature reading on the groundstation is -103*C. This bug had to do with an erroneous line of code which prompted the IMU to ‘use’ an external oscillator crystal instead of its own clock, and it did not have an external oscillator crystal soldered onto the breakout board. With that bug fixed, the CubeSat was functioning fully as intended, and I completed the final printing of the walls and the lid for its final assembly. Photos are shown below of intermediate final assembly stages, and then the fully assembled final product.

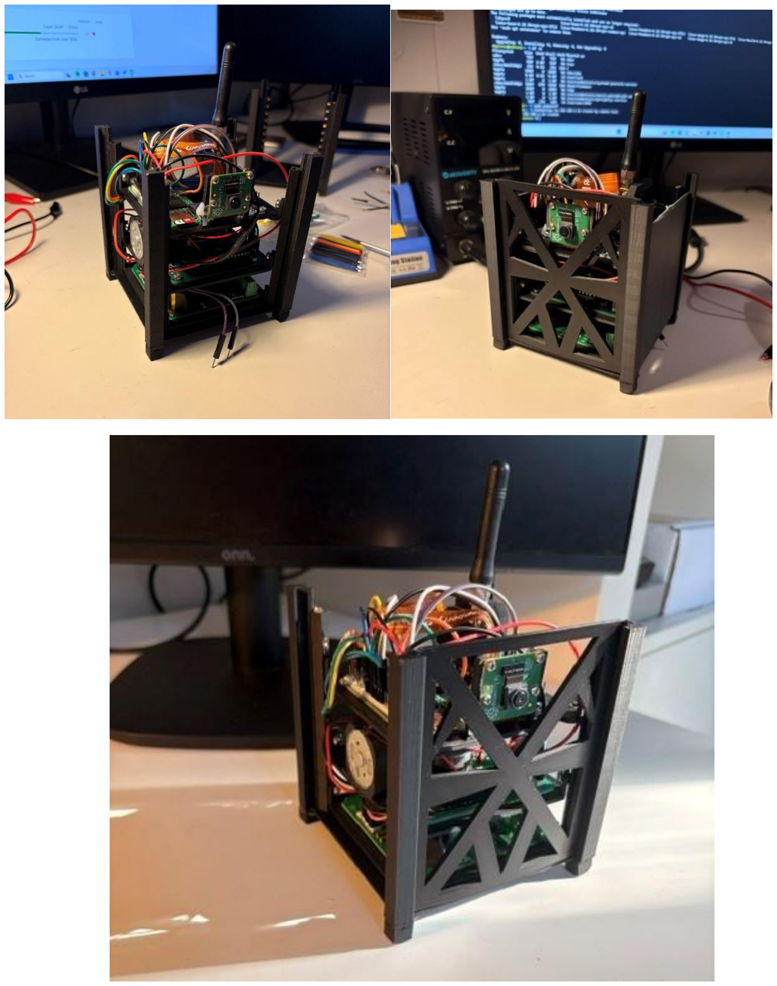
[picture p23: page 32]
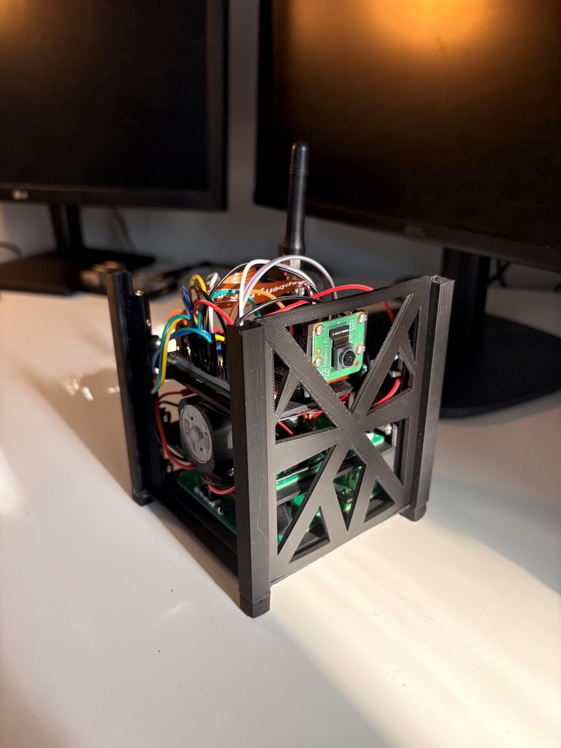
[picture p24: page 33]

Figure 36- Photos of various stages of final CubeSat assembly

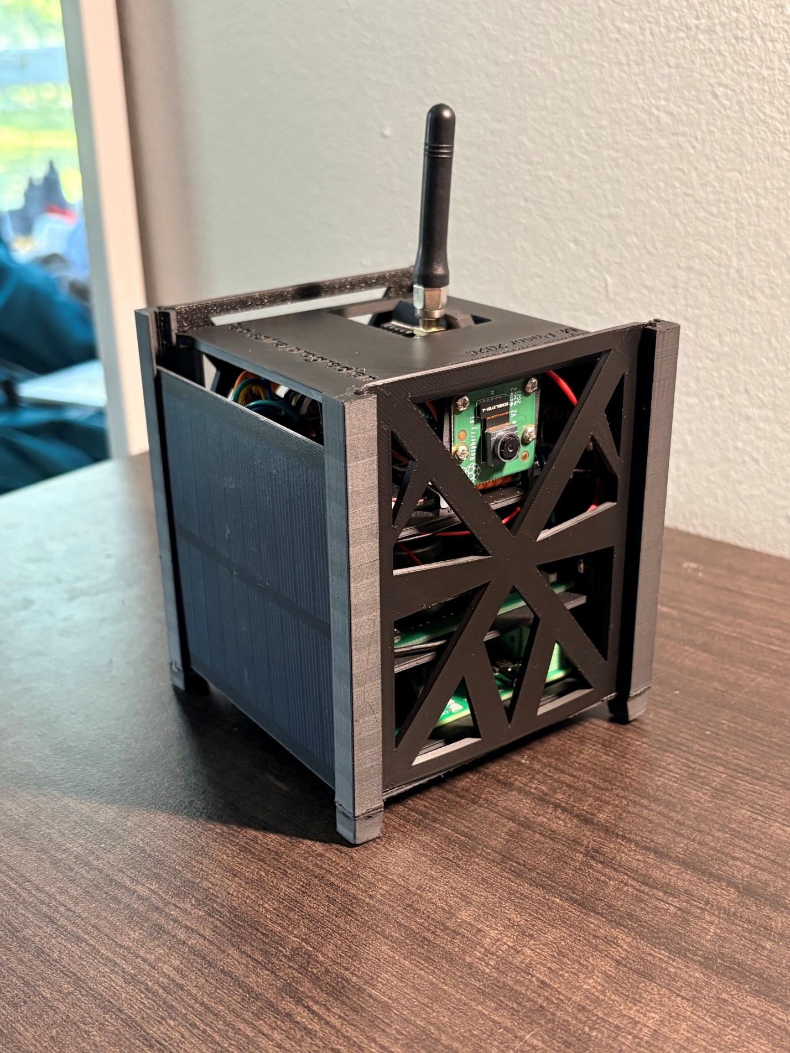
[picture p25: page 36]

Figure 37- Mjolnir CubeSat, Mk.I

Reflecting on the completion of this project, I definitely was ambitious in my undertaking. I very much underestimated the amount of work and hours which would go into this project, however the constant practice meant that things such as 3D design and PCB design became like second nature. I could easily sit down within the span of an afternoon and knock out a print or a PCB for a specific function after the completion of this project.
Moreso, I am very proud to have completed this project. In terms of feature comparisons and complexity, this project blows my desktop robotic arm out of the water. I faced great challenges over the course of this project and had to think creatively to solve them, which was a nice challenge. I think for my next project (whenever that happens) I’d like to tone down the scope a little bit, to focus on something akin to a singular ‘subsystem’ or component. I say this because the mechanical design, PCB design, and programming of this project felt like mini projects in and of themselves. I did have a great time learning about all things space and applying some of my knowledge to a potentially industry relevant project, and I accomplished my initial goal to improve my skills in electronic and PCB design.
And, at the end of it all, I may be in the running for the world’s most complex desk ornament!

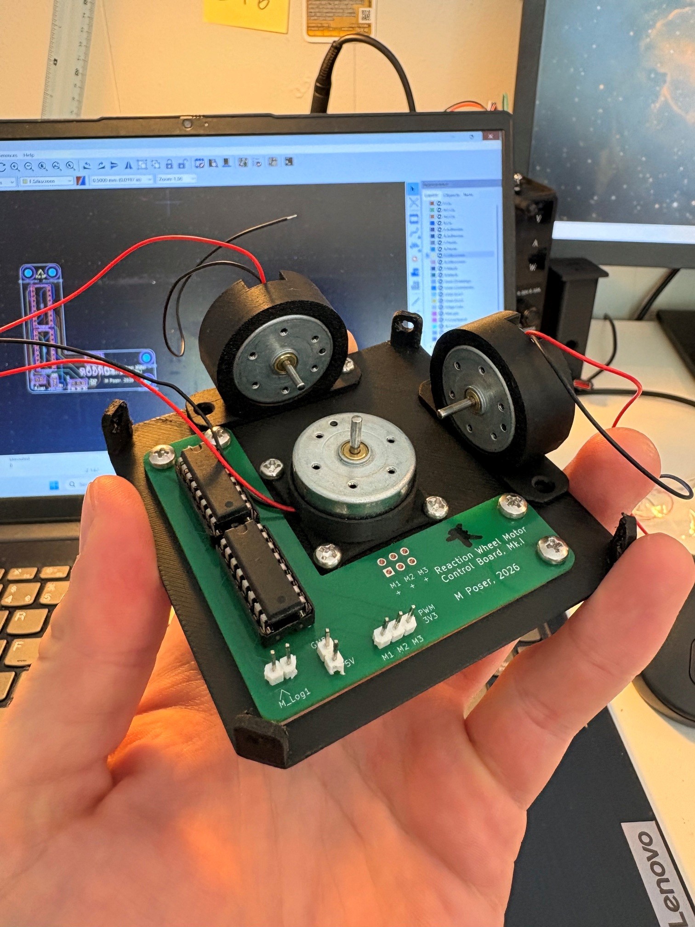
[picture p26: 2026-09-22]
Design_Documentation/Photos/LinkedIn Post/motor control PCB.jpg

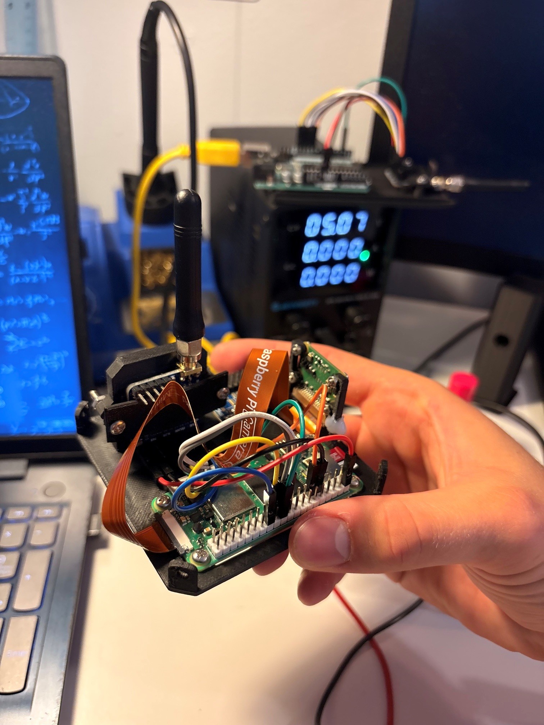
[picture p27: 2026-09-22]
Design_Documentation/Photos/top tray 4.jpg

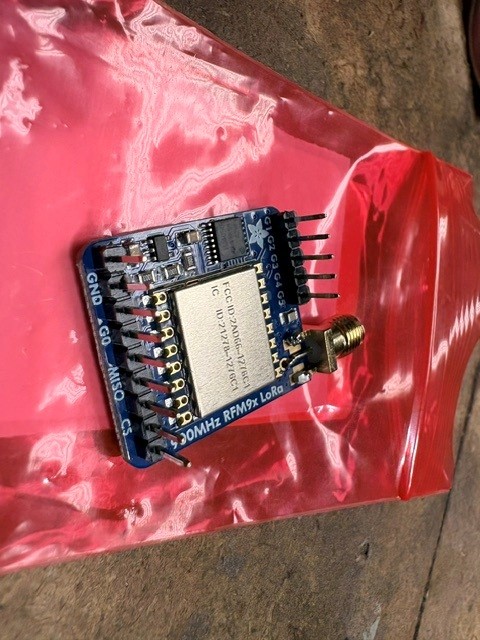
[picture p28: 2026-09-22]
Design_Documentation/Photos/Lora 2.jpg

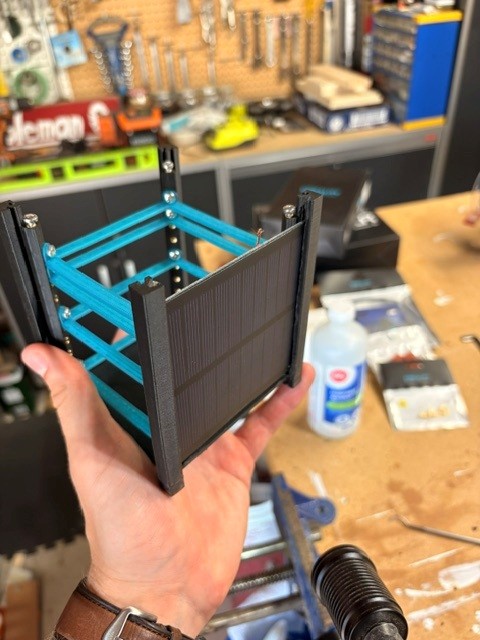
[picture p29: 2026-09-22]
Design_Documentation/Photos/trays 3.jpg

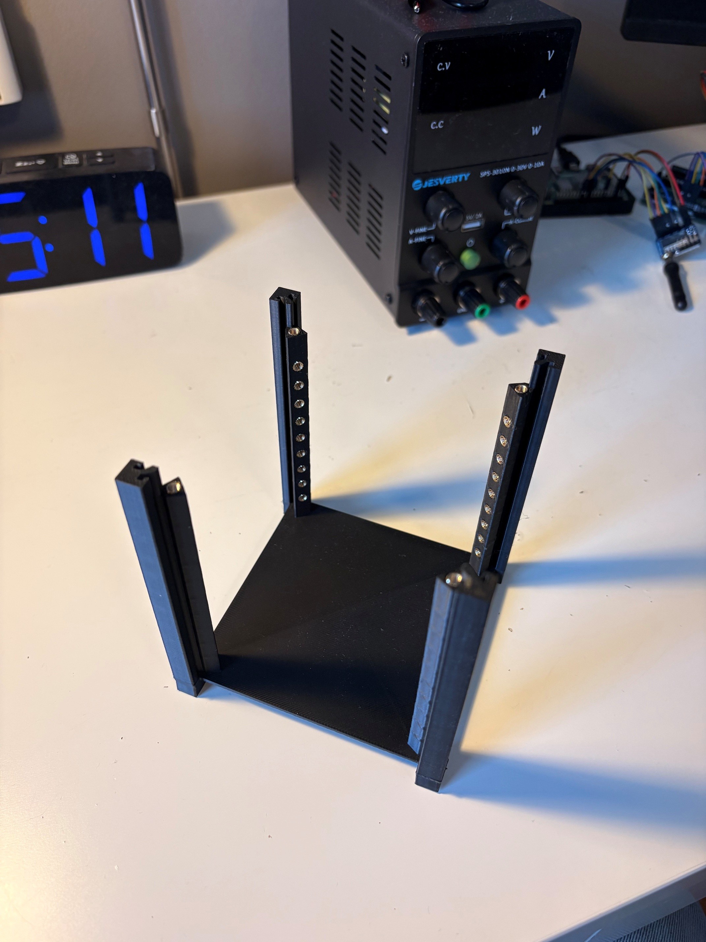
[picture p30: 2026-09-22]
Design_Documentation/Photos/frame.jpg

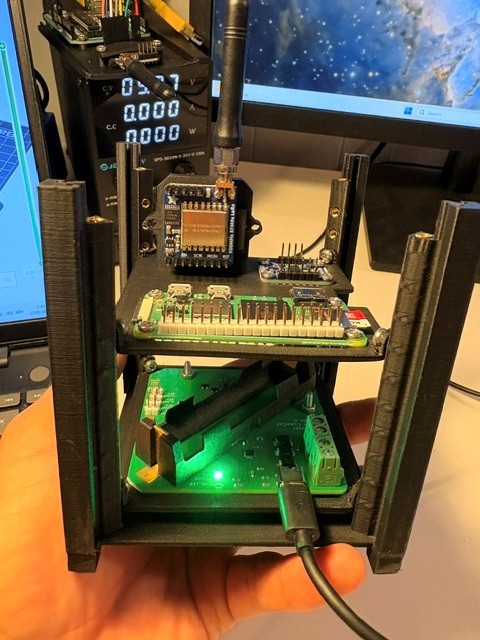
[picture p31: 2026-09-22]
Design_Documentation/Photos/top tray 3.jpg

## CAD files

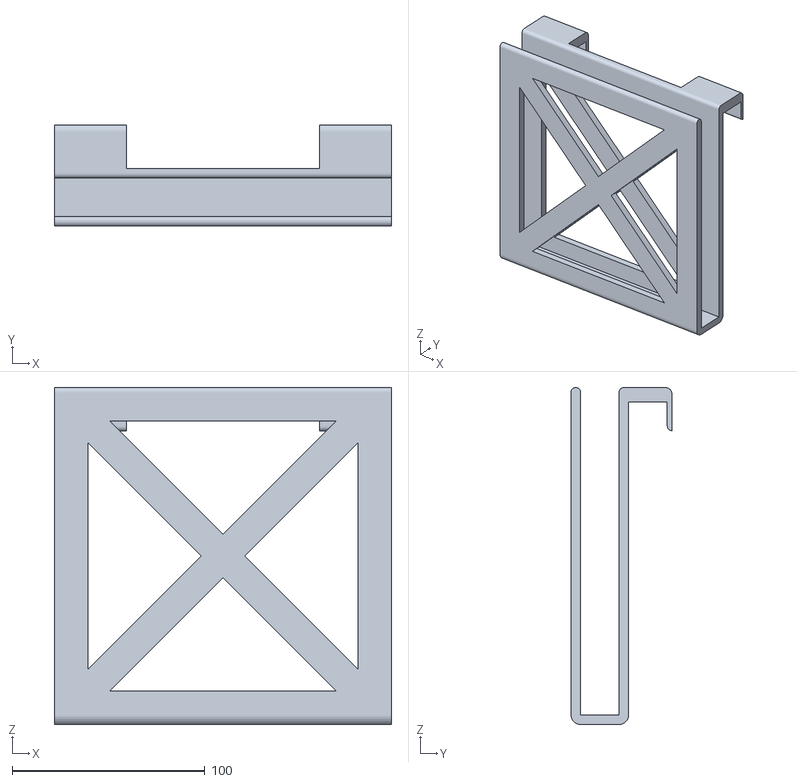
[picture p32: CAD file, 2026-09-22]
Design_Documentation/Fusion360/STL/Keyboard Mount.stl
175.0 x 52.5 x 175.0

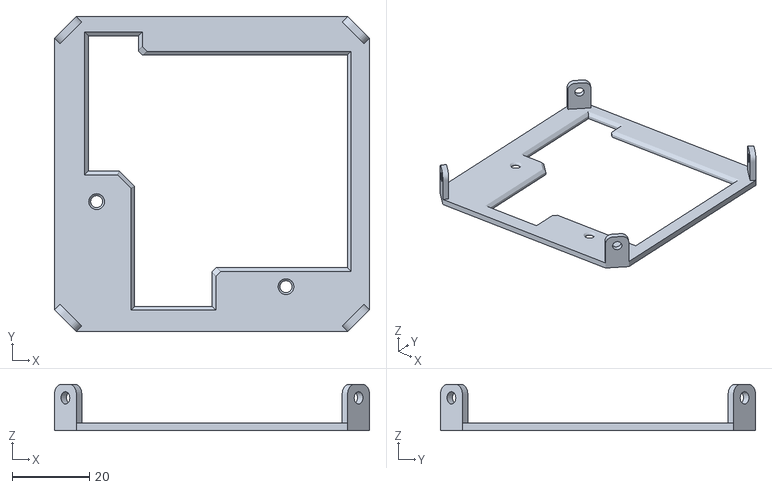
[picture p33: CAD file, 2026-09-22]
Design_Documentation/Fusion360/STL/BMS Tray.stl
81.5 x 81.5 x 12.0

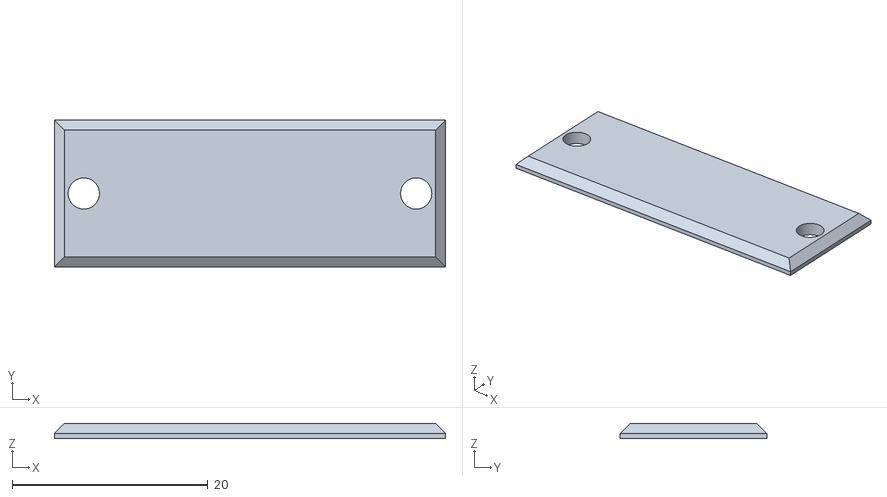
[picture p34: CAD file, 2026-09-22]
Design_Documentation/Fusion360/STL/LoRA Fastener.stl
40.0 x 15.0 x 1.50

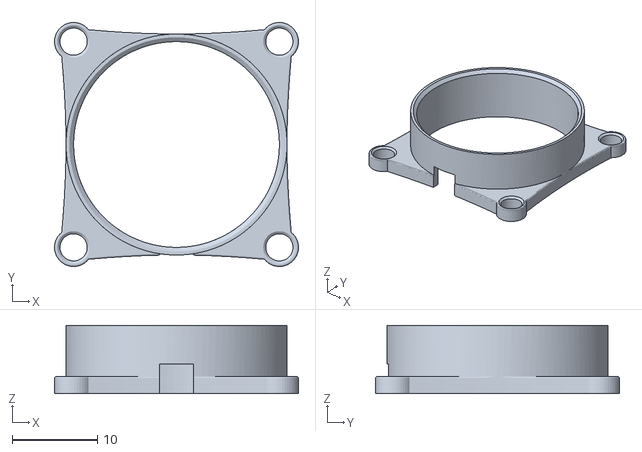
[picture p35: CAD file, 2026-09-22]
Design_Documentation/Fusion360/STL/z axis motor mount.stl
28.7 x 28.7 x 8.00

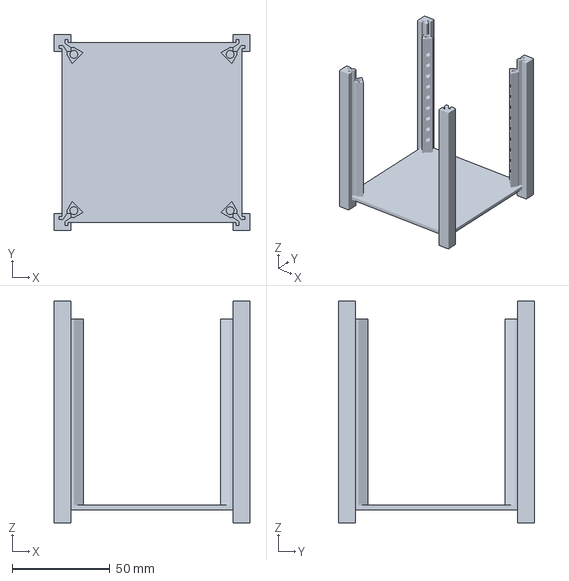
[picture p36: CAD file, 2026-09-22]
Design_Documentation/Fusion360/STL/CubeSat Outer Frame, Mk.I.3mf
100.0 x 100.0 x 113.5 mm

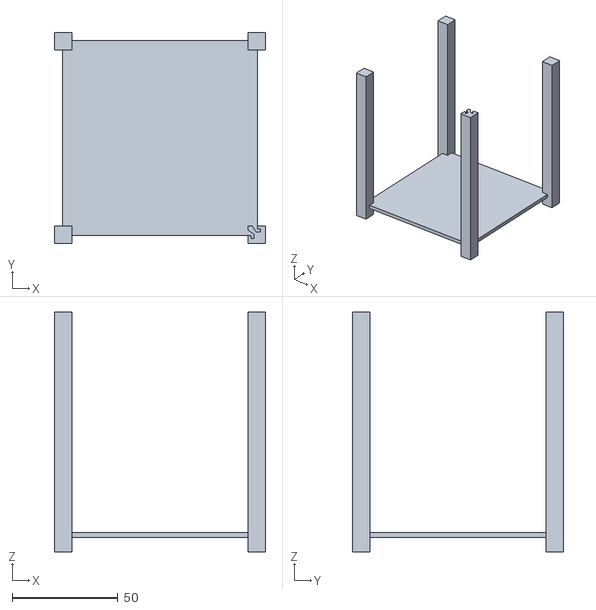
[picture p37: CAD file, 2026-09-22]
Design_Documentation/Fusion360/STL/CubeSat Outer Frame (Mk.I test).stl
100.0 x 100.0 x 113.5

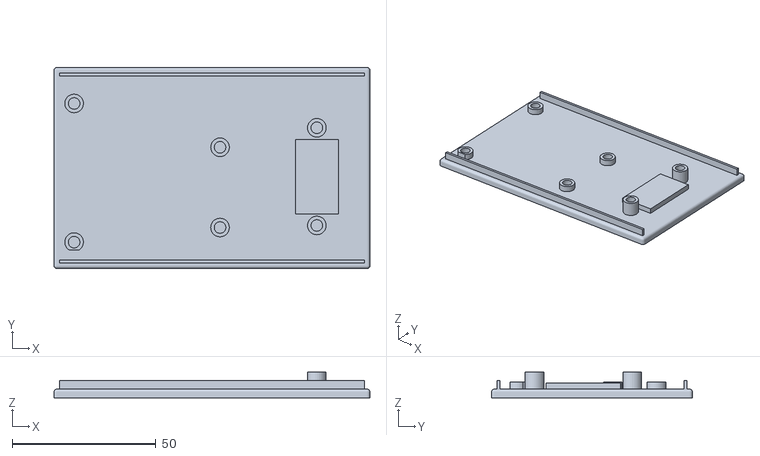
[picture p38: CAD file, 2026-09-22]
Design_Documentation/Fusion360/STL/GroundStation Base.stl
110.0 x 70.0 x 8.90

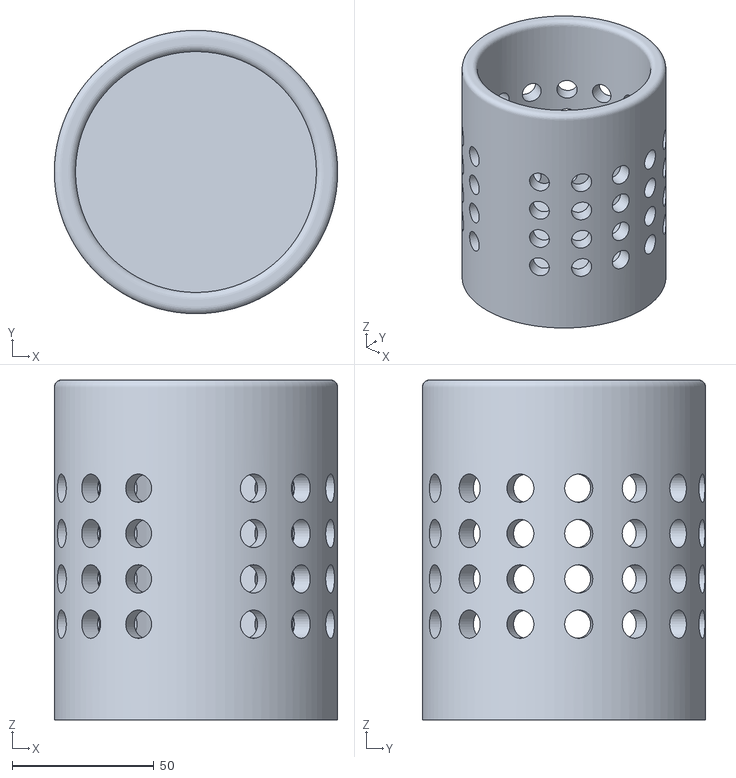
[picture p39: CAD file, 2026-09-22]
Design_Documentation/Fusion360/STL/Cable Cup.stl
100.0 x 100.0 x 120.0

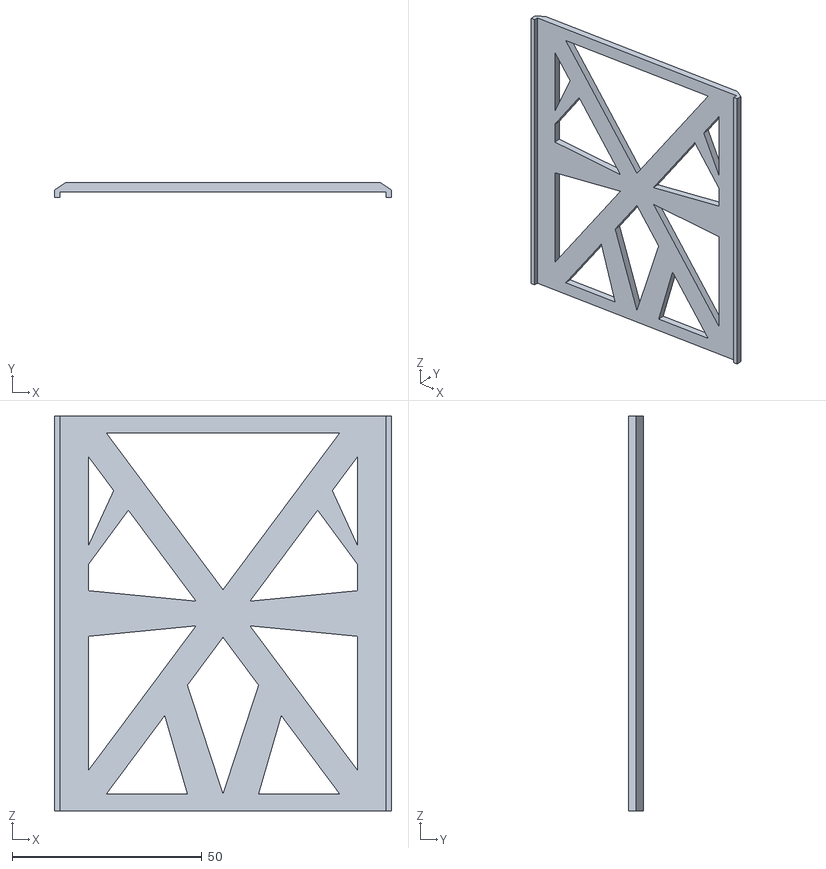
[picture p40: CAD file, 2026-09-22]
Design_Documentation/Fusion360/STL/CubeSat_Walls.stl
88.8 x 4.00 x 104.0

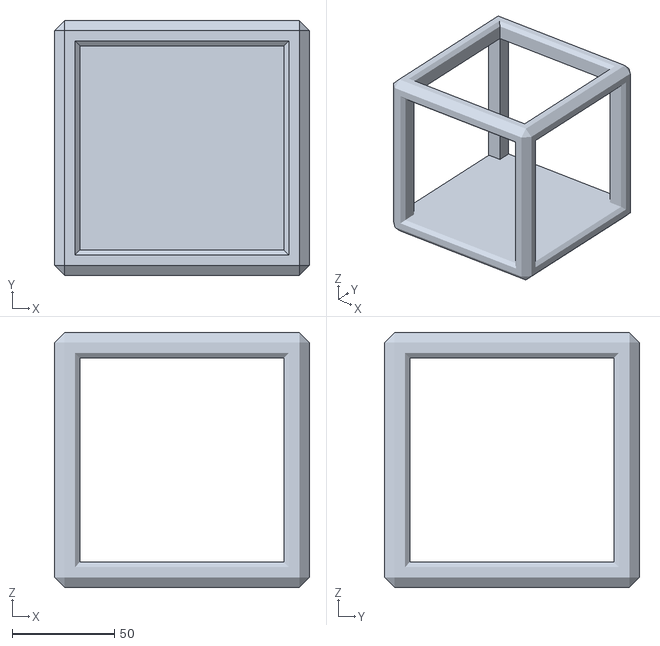
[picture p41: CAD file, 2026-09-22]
Design_Documentation/Fusion360/STL/CubeSat Measurement Frame.stl
125.0 x 125.0 x 125.0

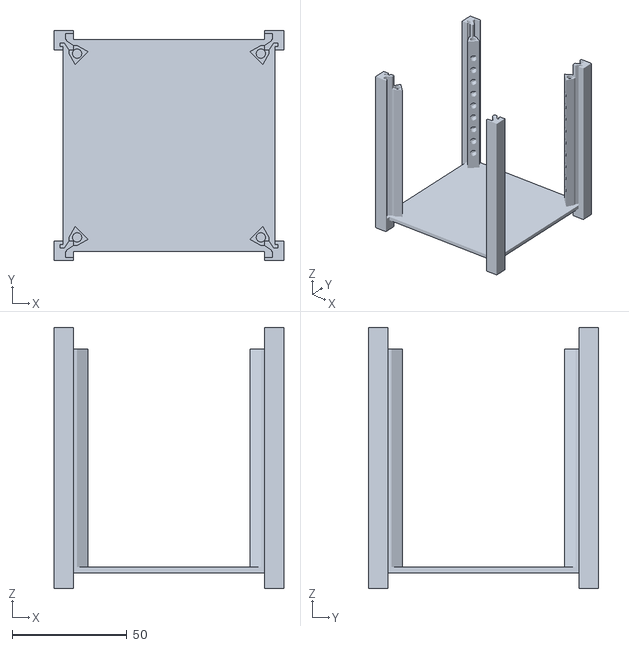
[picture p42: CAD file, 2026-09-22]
Design_Documentation/Fusion360/STL/CubeSat Outer Frame, Mk.II.stl
100.0 x 100.0 x 113.5

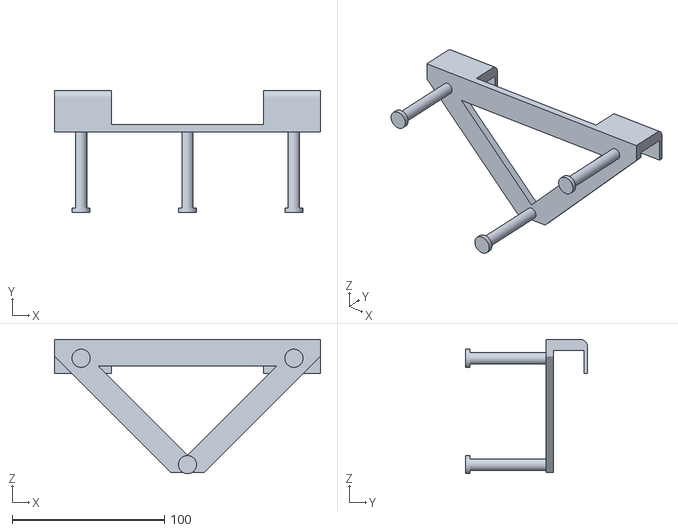
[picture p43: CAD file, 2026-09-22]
Design_Documentation/Fusion360/STL/Monitor Cable Mount.stl
175.0 x 80.5 x 88.5

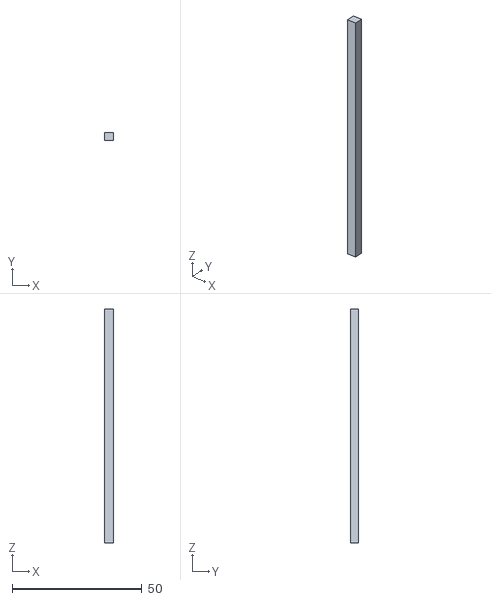
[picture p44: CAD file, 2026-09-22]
Design_Documentation/Fusion360/STL/Solar Panel Slats.stl
3.50 x 3.23 x 90.0

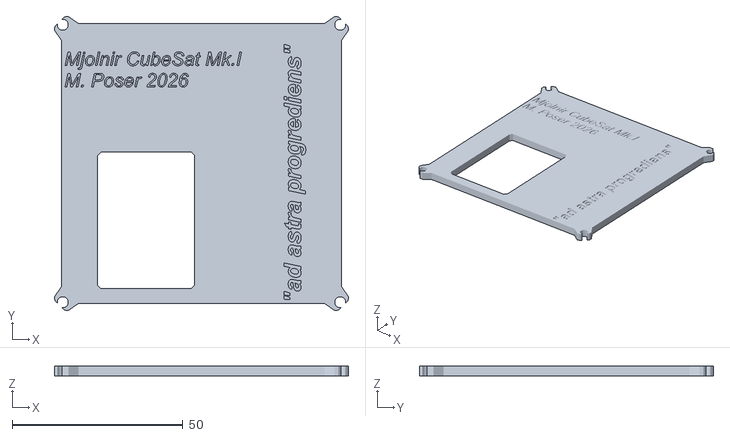
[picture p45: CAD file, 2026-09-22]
Design_Documentation/Fusion360/STL/CubeSat_Lid.stl
86.2 x 86.2 x 3.00

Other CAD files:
Design_Documentation/Fusion360/STL/Reaction Wheel Tray.stl
Design_Documentation/Fusion360/STL/xy axis motor mount.stl
Design_Documentation/Fusion360/STL/Heat Set Insert Hole Test.stl
Design_Documentation/Fusion360/STL/Reaction_Wheel.stl
Design_Documentation/Fusion360/STL/CubeSat Outer Frame, Mk.I.stl
Design_Documentation/Fusion360/STL/CubeSat Tray Template.stl
Design_Documentation/Fusion360/STL/Flight Computer Tray.stl
Design_Documentation/Fusion360/STL/LoRA Fastener Long.stl

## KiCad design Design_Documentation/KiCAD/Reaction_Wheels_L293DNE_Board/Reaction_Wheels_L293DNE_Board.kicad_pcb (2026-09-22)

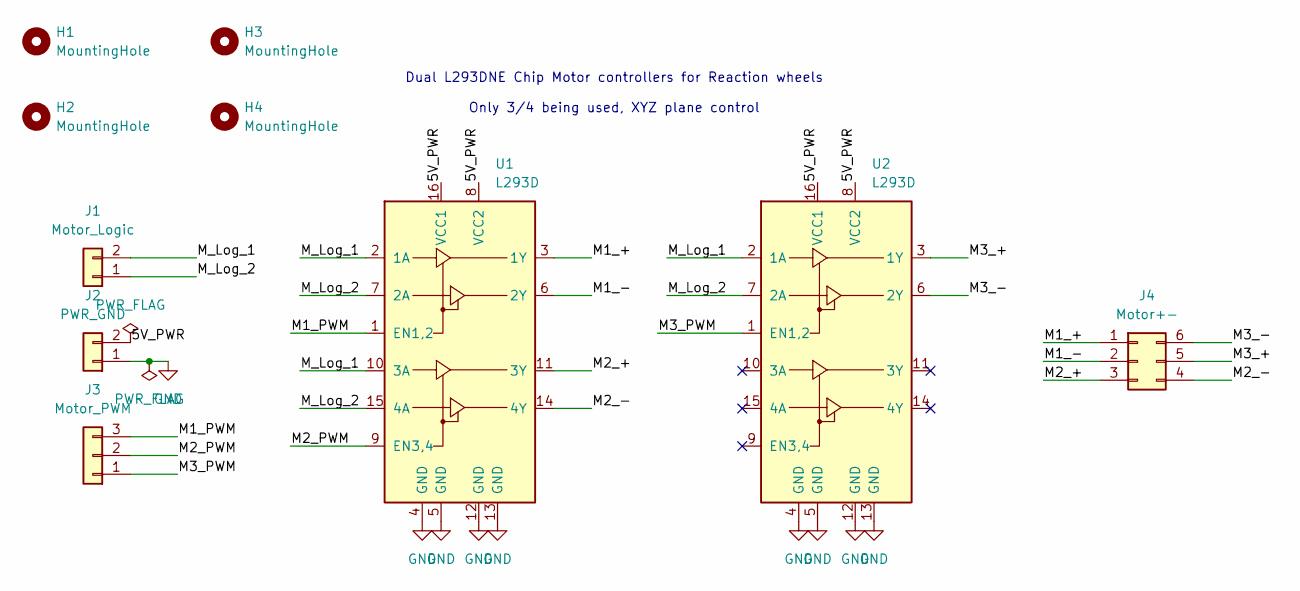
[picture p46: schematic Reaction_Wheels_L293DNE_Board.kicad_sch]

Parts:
H1, H2, H3, H4: MountingHole; MountingHole_3.2mm_M3
J1: Motor_Logic; PinHeader_1x02_P2.54mm_Vertical
J2: PWR_GND; PinHeader_1x02_P2.54mm_Vertical
J3: Motor_PWM; PinHeader_1x03_P2.54mm_Vertical
J4: Motor+-; PinHeader_2x03_P2.54mm_Vertical
U1, U2: L293D; DIP-16_W7.62mm

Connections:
/5V_PWR: J2.2, U1.8 (VCC2), U1.16 (VCC1), U2.8 (VCC2), U2.16 (VCC1)
/M1_+: J4.1, U1.3 (1Y)
/M1_-: J4.2, U1.6 (2Y)
/M1_PWM: J3.3, U1.1 (EN1,2)
/M2_+: J4.3, U1.11 (3Y)
/M2_-: J4.4, U1.14 (4Y)
/M2_PWM: J3.2, U1.9 (EN3,4)
/M3_+: J4.5, U2.3 (1Y)
/M3_-: J4.6, U2.6 (2Y)
/M3_PWM: J3.1, U2.1 (EN1,2)
/M_Log_1: J1.2, U1.2 (1A), U1.10 (3A), U2.2 (1A)
/M_Log_2: J1.1, U1.7 (2A), U1.15 (4A), U2.7 (2A)
GND: J2.1, U1.4 (GND), U1.5 (GND), U1.12 (GND), U1.13 (GND), U2.4 (GND), U2.5 (GND), U2.12 (GND), U2.13 (GND)

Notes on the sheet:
Dual L293DNE Chip Motor controllers for Reaction wheels Only 3/4 being used, XYZ plane control

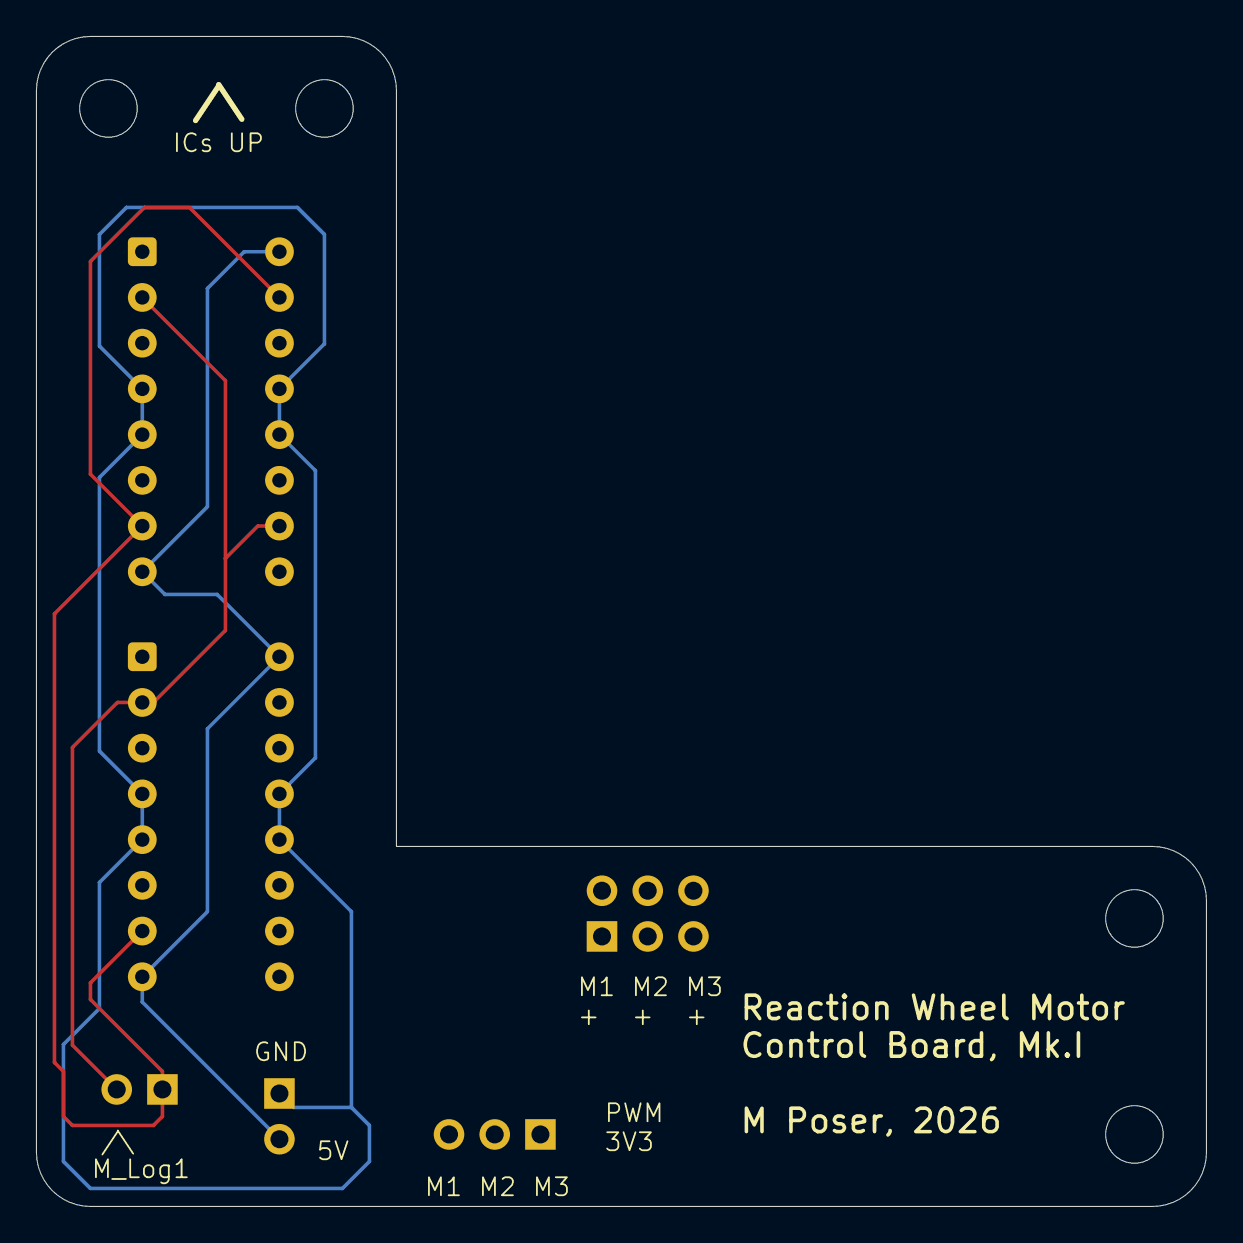
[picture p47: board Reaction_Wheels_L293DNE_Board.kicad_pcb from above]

Board: 4 copper layers, 65.0 x 65.0 mm, 10 parts (0 on the bottom side), 13 nets.

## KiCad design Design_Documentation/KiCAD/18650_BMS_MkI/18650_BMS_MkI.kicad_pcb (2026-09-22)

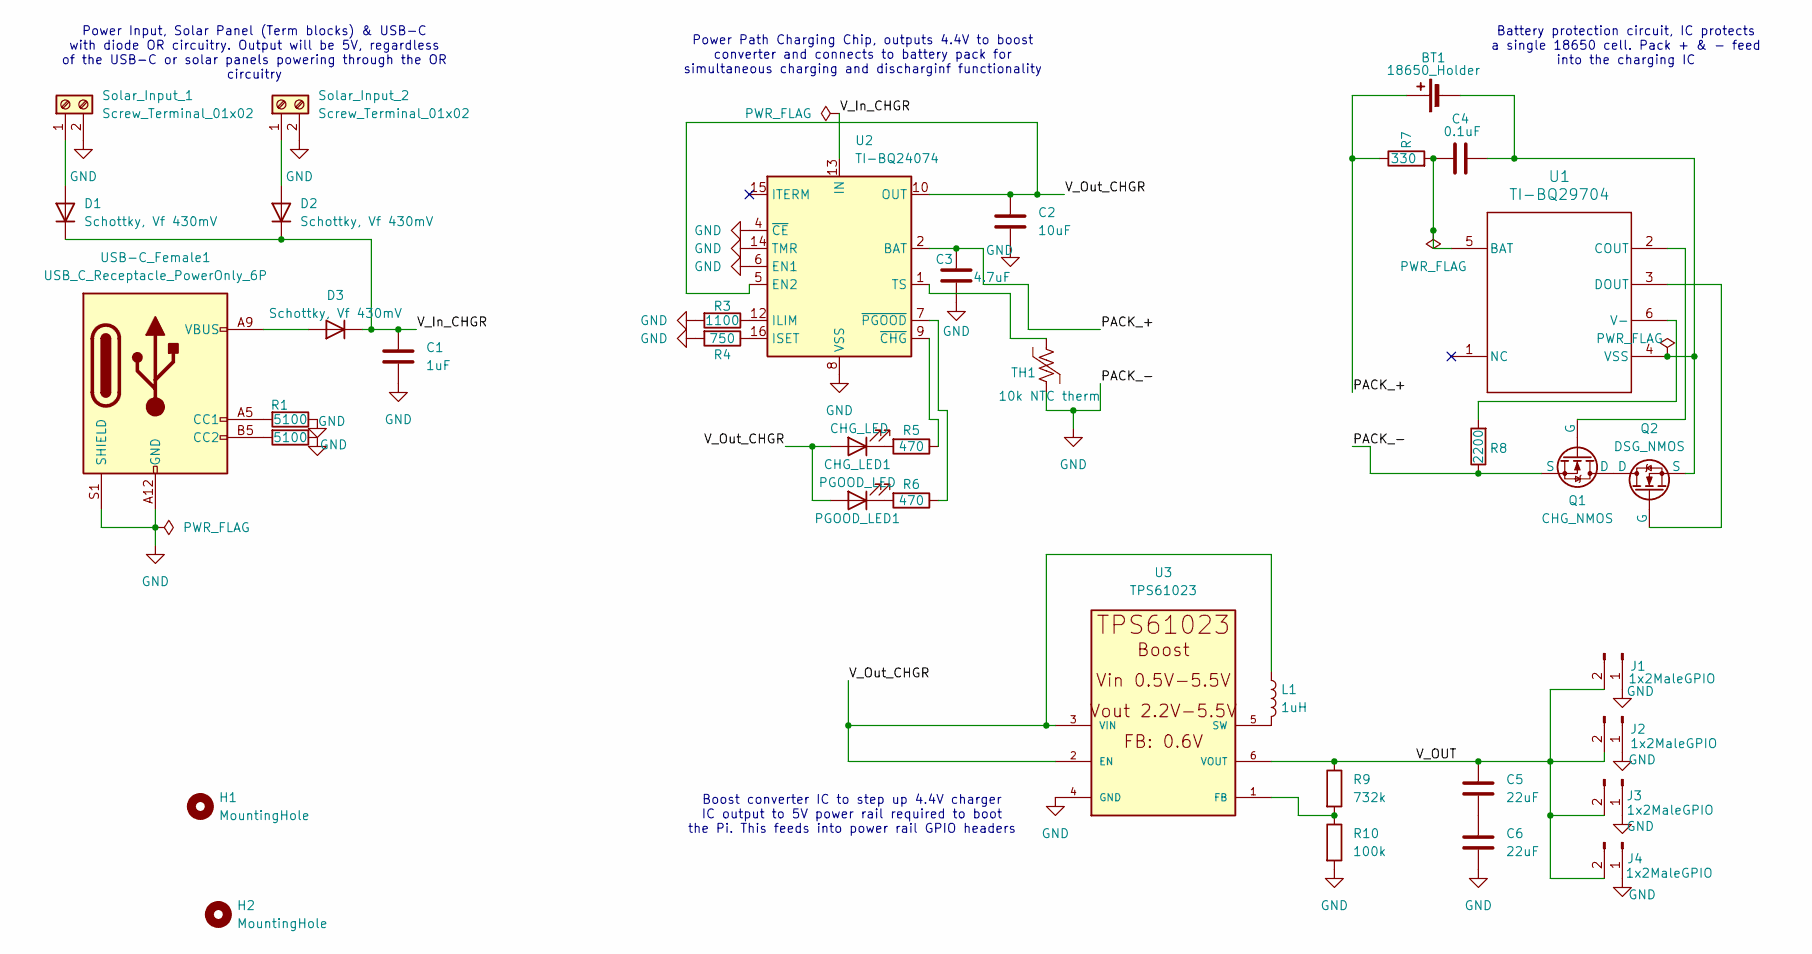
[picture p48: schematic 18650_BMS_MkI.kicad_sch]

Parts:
BT1: 18650_Holder; BatteryHolder_Keystone_1042_1x18650
C1: 1uF; C_0603_1608Metric
C2: 10uF; C_0603_1608Metric
C3: 4.7uF; C_0603_1608Metric
C4: 0.1uF; C_0603_1608Metric
C5, C6: 22uF; C_1206_3216Metric
CHG_LED1: CHG_LED; LED_1206_3216Metric
D1, D2, D3: Schottky, Vf 430mV; D_SMB
H1, H2: MountingHole; MountingHole_3.2mm_M3
J1, J2, J3, J4: 1x2MaleGPIO; PinHeader_1x02_P2.54mm_Vertical
L1: 1uH; L_1210_3225Metric
PGOOD_LED1: PGOOD_LED; LED_1206_3216Metric
Q1: CHG_NMOS; SOT-23-3
Q2: DSG_NMOS; SOT-23-3
R1, R2: 5100; R_0603_1608Metric
R3: 1100; R_0603_1608Metric
R4: 750; R_0603_1608Metric
R5, R6: 470; R_0603_1608Metric
R7: 330; R_0603_1608Metric
R8: 2200; R_0603_1608Metric
R9: 732k; R_0603_1608Metric
R10: 100k; R_0603_1608Metric
Solar_Input_1, Solar_Input_2: Screw_Terminal_01x02; TerminalBlock_Phoenix_PT-1,5-2-5.0-H_1x02_P5.00mm_Horizontal
TH1: 10k NTC therm; R_0603_1608Metric
U1: TI-BQ29704; DSE0006A
U2: TI-BQ24074; VQFN-16-1EP_3x3mm_P0.5mm_EP1.6x1.6mm_ThermalVias
U3: TPS61023; SOT-563; DigiKey_Part_Number 296-TPS61023DRLRCT-ND
USB-C_Female1: USB_C_Receptacle_PowerOnly_6P; USB_C_Receptacle_GCT_USB4125-xx-x_6P_TopMnt_Horizontal

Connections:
/PACK_+: BT1.1 (+), C3.1, R7.1, U2.2 (BAT), U2.3 (BAT)
/V_In_CHGR: C1.1, D1.1 (K), D2.1 (K), D3.1 (K), U2.13 (IN)
/V_OUT: C5.1, J1.2, J2.2, J3.2, J4.2, R9.1, U3.6 (VOUT)
/V_Out_CHGR: C2.1, CHG_LED1.2 (A), L1.1, PGOOD_LED1.2 (A), U2.5 (EN2), U2.10 (OUT), U2.11 (OUT), U3.2 (EN), U3.3 (VIN)
GND: C1.2, C2.2, C3.2, C6.2, J1.1, J2.1, J3.1, J4.1, Q1.3 (S), R1.1, R2.1, R3.2, R4.2, R8.1, R10.2, Solar_Input_1.2, Solar_Input_2.2, TH1.2, U2.4 (~CE), U2.6 (EN1), U2.8 (VSS), U2.14 (TMR), U2.17 (VSS), U3.4 (GND), USB-C_Female1.A12 (GND), USB-C_Female1.B12 (GND), USB-C_Female1.S1 (SHIELD)
unnamed: BT1.2 (-), C4.1, Q2.3 (S), U1.4 (VSS)
unnamed: C5.2, C6.1
unnamed: CHG_LED1.1 (K), R5.2
unnamed: D1.2 (A), Solar_Input_1.1
unnamed: D2.2 (A), Solar_Input_2.1
unnamed: D3.2 (A), USB-C_Female1.A9 (VBUS), USB-C_Female1.B9 (VBUS)
unnamed: PGOOD_LED1.1 (K), R6.2
unnamed: Q1.1 (D), Q2.1 (D)
unnamed: Q1.2 (G), U1.2 (COUT)
unnamed: Q2.2 (G), U1.3 (DOUT)
unnamed: C4.2, R7.2, U1.5 (BAT)
unnamed: R8.2, U1.6 (V-)
unnamed: R3.1, U2.12 (ILIM)
unnamed: R4.1, U2.16 (ISET)
unnamed: TH1.1, U2.1 (TS)
unnamed: R5.1, U2.9 (~CHG)
unnamed: R6.1, U2.7 (~PGOOD)
unnamed: R9.2, R10.1, U3.1 (FB)
unnamed: L1.2, U3.5 (SW)
unnamed: R1.2, USB-C_Female1.A5 (CC1)
unnamed: R2.2, USB-C_Female1.B5 (CC2)

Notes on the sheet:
Battery protection circuit, IC protects a single 18650 cell. Pack + & - feed into the charging IC
Boost converter IC to step up 4.4V charger IC output to 5V power rail required to boot the Pi. This feeds into power rail GPIO headers
Power Path Charging Chip, outputs 4.4V to boost converter and connects to battery pack for simultaneous charging and discharginf functionality
Power Input, Solar Panel (Term blocks) & USB-C with diode OR circuitry. Output will be 5V, regardless of the USB-C or solar panels powering through the OR circuitry

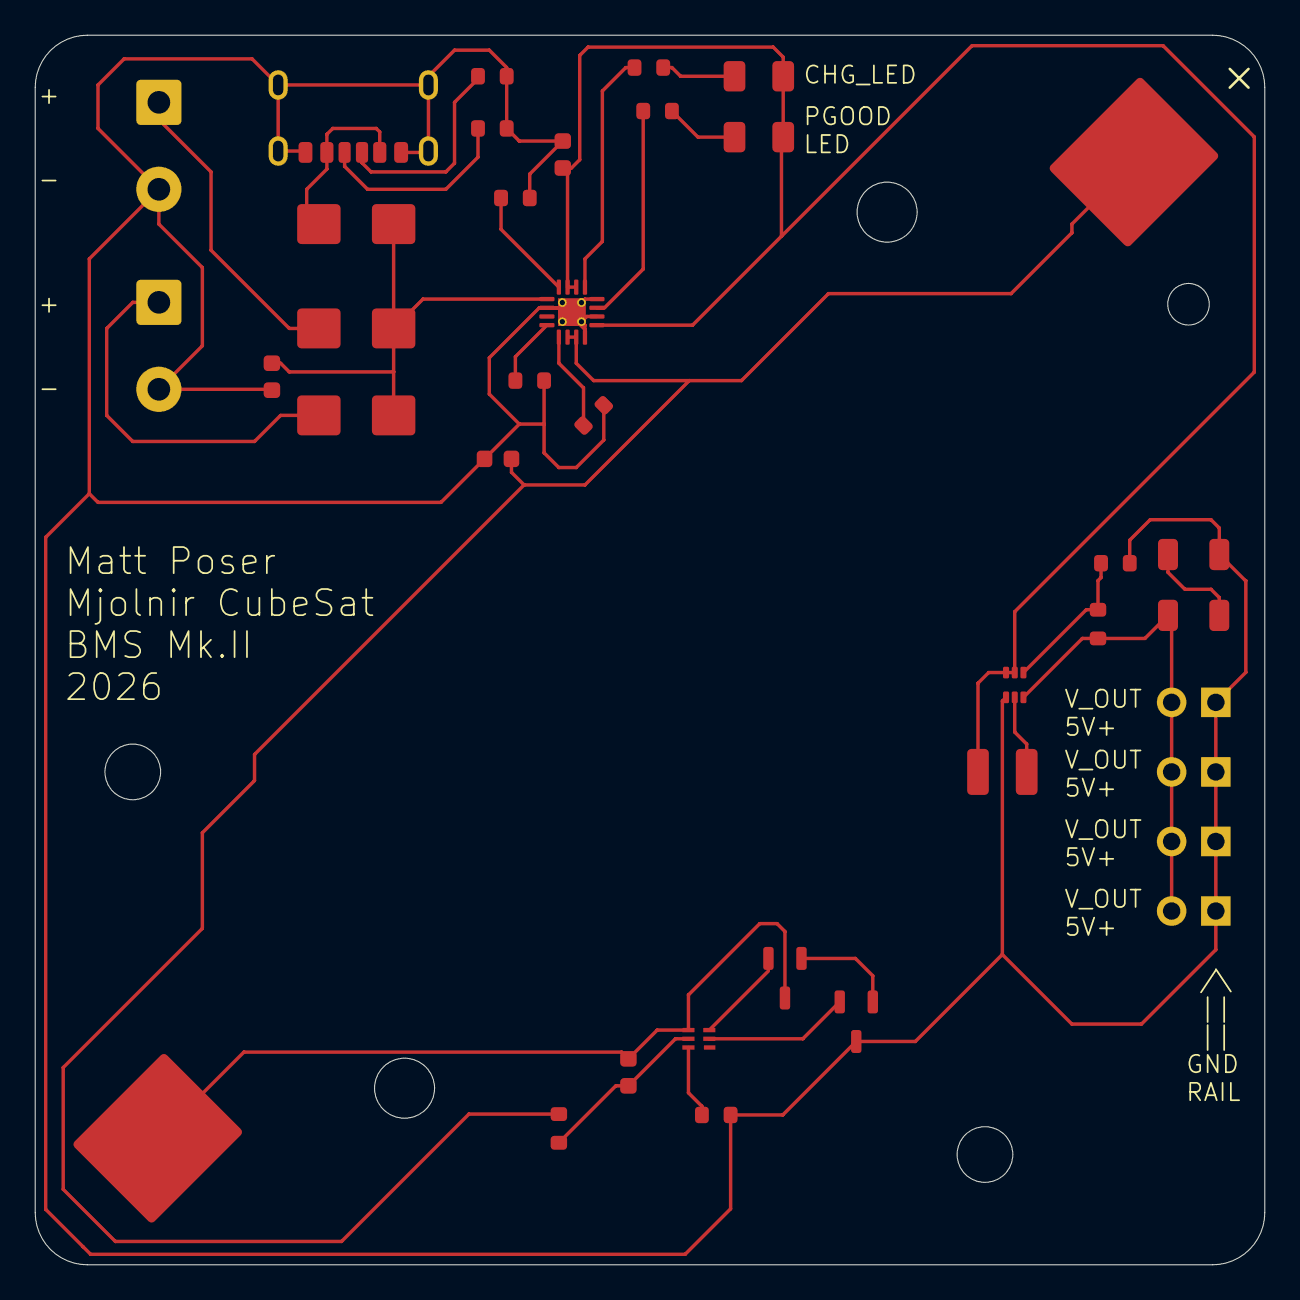
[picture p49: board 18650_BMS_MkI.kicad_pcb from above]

Board: 2 copper layers, 70.7 x 70.7 mm, 38 parts (0 on the bottom side), 26 nets.

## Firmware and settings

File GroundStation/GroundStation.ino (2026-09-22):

/*
Matt Poser, 11:49pm April 28th 2026
This script is for the ground station radio uplink/downlink comms operation

essentially, the groundstation UI and python backend will 
interact with the associated serial bus, once this script is spun up

this script will operate the uplink and downlink functionality of the groundstation
& LoRa radio module based on the architecture seen in the word doc

it will operate mainly as a listening device, reading telemetry command
packets off the radio and writing them to the serial bus as output

if a command is placed in the serial bus, it will begin its broadcast to the
satellite

let's see how well it works!
*/

#include <SPI.h>
#include <RH_RF95.h>
#include <ArduinoJson.h>
#include <RHReliableDatagram.h>

//constants
#define RFM95_CS   10
#define RFM95_RST   9
#define RFM95_INT   2
#define RF95_FREQ   915.0
#define BAUD_RATE 115200
#define CUBESAT_ADDR       1   //rfm9x.node on the satellite
#define GROUNDSTATION_ADDR 2   //Groundstation node. These values match python script

//variables
uint16_t groundstation_timeout = 30000; //milliseconds
uint8_t buf[RH_RF95_MAX_MESSAGE_LEN + 1];
String cubesat_sensor_packet = "";
String groundstation_command = "";



RH_RF95 rf95(RFM95_CS, RFM95_INT);
RHReliableDatagram manager(rf95, GROUNDSTATION_ADDR); //need manager for 'recieve with ack' functionality

void setup() {
    Serial.begin(BAUD_RATE); //fastest supported on the device
    while (!Serial);

    pinMode(RFM95_RST, OUTPUT);
    digitalWrite(RFM95_RST, HIGH);
    delay(10); //milliseconds
    //board reset
    digitalWrite(RFM95_RST, LOW);
    delay(10);
    digitalWrite(RFM95_RST, HIGH);
    delay(10);


    //manager and frequency inits
    if (!manager.init()) {
    Serial.println("radio init failed");
    while (1);
    }
    if (!rf95.setFrequency(RF95_FREQ)) {
        Serial.println("setFrequency failed");
        while (1);
    }

    //publish with ack parameters
    manager.setRetries(5);
    manager.setTimeout(1000); //double the timeout value on the
    //flight computer for when it publishes commands

    //serial read timeout value
    Serial.setTimeout(2); //very small, essentially an instantaneous check

}


void loop(){
    //this is our groundstation flow of code, which deals with
    //radio comms but also serial printing for the python backend
    //flow of the code is as follows:

    //step 1: listen for incoming packets from the CubeSat
    //how long does this function run for???
    //I think I am going to make it 'blocking' (ie,
    //will wait for much longer than i need it to)
    cubesat_sensor_packet = GroundStationListen(groundstation_timeout);

    //step 2: check the serial bus for commands from python
    //if command recieved, publish command to CubeSat
    //if not, do nothing
    //once done, clear buffer and eliminate queued messages
    if (Serial.available() > 0) { //if there is anything in the buffer
        groundstation_command = Serial.readString(); //'instantaneous'
        //call publish function, to cubesat
        GroundStationPublish(groundstation_command);
        //clear buffer
        clearSerialBuffer();
    }

    //step 3: write CubeSat data packet to serial, for python
    //backend to push to API/frontend
    //this function is instantaneous, and message will be stored in
    //the laptop's serial buffer
    Serial.println(cubesat_sensor_packet);

}



String GroundStationListen(uint16_t timeout){
    //in this function, we will retrieve the sensor packet
    //1. Listen with ack, 30s groundstation timer
    uint8_t len = RH_RF95_MAX_MESSAGE_LEN;
    uint8_t from;
    bool success = manager.recvfromAckTimeout(buf, &len, timeout, &from);

    //2. decode bytes into string (if message returned is valid)
    //if not, return "INVALID PACKET"
    if (!success) return "NO PACKET RECIEVED, 30s TIMEOUT";
    buf[len] = '\0';

    //3. return string object, decoded from bytes
    return String((char*)buf);
}


void GroundStationPublish(String cmd){
    //publish with ack command goes here, should be one line(?)
    manager.sendtoWait((uint8_t *)cmd.c_str(), cmd.length(), CUBESAT_ADDR);
    return;
}


void clearSerialBuffer() {
    while (Serial.available() > 0) {
        Serial.read();
    }
}  //claude wrote this, apparently Serial.flush() doesn't work in the way I think

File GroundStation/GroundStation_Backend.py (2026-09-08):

"""
M Poser, August 19th 2026
This is the script which uses the web API to broadcast packets coming from the Arduino
up to the local JS frontend. It is a simple thru/script, with it's main role to be
reading the packets coming from the Arduino, and occasionally sending a formatted command
along the serial bus to the Arduino to then send to the cubesat

Run with:  python GroundStation_Backend.py

Serves a WebSocket at ws://localhost:8765/serial that the frontend's
SerialTerminal widget connects to. Each completed line read off the
Arduino's serial port is broadcast to every connected browser tab as
its own text message.

Also serves POST /command — the frontend's command button hits this
to queue a string that gets written out to the Arduino on the next
reader-thread cycle (commands are expected to be infrequent).
"""
import asyncio
import queue
import threading
import time
import serial
import serial.tools.list_ports
from fastapi import FastAPI, WebSocket, WebSocketDisconnect
from fastapi.middleware.cors import CORSMiddleware
from pydantic import BaseModel

BAUD = 115200
PORT_SCAN_INTERVAL = 2.0  # seconds between retries while no Arduino is found

app = FastAPI()
# The frontend (Vite dev server) runs on a different origin than this
# backend, so the browser blocks the /command POST without this — the
# WebSocket connection isn't affected since browsers don't apply CORS
# to it the same way.
app.add_middleware(
    CORSMiddleware,
    allow_origins=["*"],
    allow_methods=["*"],
    allow_headers=["*"],
)
clients: set[WebSocket] = set()
line_queue: asyncio.Queue[str] = asyncio.Queue()

# Thread-safe hand-off for outgoing commands: the FastAPI endpoint (event
# loop thread) puts here, the serial reader (background thread) drains it.
# A plain queue.Queue is used rather than asyncio.Queue because the
# consumer lives outside the event loop.
command_queue: queue.Queue[str] = queue.Queue()


class CommandRequest(BaseModel):
    command: str


def find_arduino_port() -> str | None:
    for p in serial.tools.list_ports.comports():
        if "Arduino" in p.description:
            return p.device
    return None


def serial_reader(loop: asyncio.AbstractEventLoop) -> None:
    """Runs in a background thread (pyserial is blocking). Reconnects
    automatically if the Arduino isn't plugged in yet or drops out.

    Before each blocking read, drains at most one pending outgoing
    command (if any) and writes it out. Commands are rare, so riding
    along on the existing ~1s readline() timeout cadence is plenty
    responsive without needing a second thread or a lock on `ser`."""
    ser: serial.Serial | None = None
    while True:
        if ser is None:
            port = find_arduino_port()
            if port is None:
                time.sleep(PORT_SCAN_INTERVAL)
                continue
            try:
                ser = serial.Serial(port, BAUD, timeout=1)
            except serial.SerialException:
                ser = None
                time.sleep(PORT_SCAN_INTERVAL)
                continue

        # --- outgoing: send a queued command, if any, before reading ---
        try:
            command = command_queue.get_nowait()
        except queue.Empty:
            command = None

        if command is not None:
            try:
                ser.write(command.encode("utf-8"))  # no trailing \n —
                # the Arduino reads via a short-timeout readString(),
                # not a newline-delimited read
                asyncio.run_coroutine_threadsafe(
                    line_queue.put(f"> {command}"), loop
                )
            except serial.SerialException:
                ser.close()
                ser = None
                continue

        # --- incoming: unchanged from before ---
        try:
            raw = ser.readline()
        except serial.SerialException:
            ser.close()
            ser = None
            continue
        line = raw.decode("utf-8", errors="replace").strip()
        if line:
            asyncio.run_coroutine_threadsafe(line_queue.put(line), loop)


async def broadcaster() -> None:
    while True:
        line = await line_queue.get()
        dead = []
        for ws in clients:
            try:
                await ws.send_text(line)
            except Exception:
                dead.append(ws)
        for ws in dead:
            clients.discard(ws)


@app.on_event("startup")
async def startup() -> None:
    loop = asyncio.get_running_loop()
    threading.Thread(target=serial_reader, args=(loop,), daemon=True).start()
    asyncio.create_task(broadcaster())


@app.post("/command")
async def send_command(req: CommandRequest) -> dict:
    """Called by the frontend's command button. Queues the command for
    the serial reader thread to write out — does not block on the
    write itself, and does not wait for any response from the Arduino."""
    command_queue.put(req.command)
    return {"status": "queued", "command": req.command}


@app.websocket("/serial")
async def serial_ws(websocket: WebSocket) -> None:
    await websocket.accept()
    clients.add(websocket)
    try:
        while True:
            await websocket.receive_text()
    except WebSocketDisconnect:
        pass
    finally:
        clients.discard(websocket)


if __name__ == "__main__":
    import uvicorn

    uvicorn.run(app, host="0.0.0.0", port=8765)

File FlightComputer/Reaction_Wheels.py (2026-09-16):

#downstream script for reaction wheels functionality

#this will follow the same (rough) architecture as the Mjolnir_Reboot.py and
#Star_tracker.py scripts, but will be a little bit more depth

#this script, will take in command information, and after some initialization of
#GPIO output & PWM pins, update the state of the onboard reaction wheel controls
#the flow of the script will recieve messages in the same way as the other two,
#but will update GPIO settings instead of running a subprocess command function

import queue
import paho.mqtt.client as mqtt
import RPi.GPIO as GPIO
import re

reactionwheels_queue = queue.Queue() #initialize script local queue to store upstream command messages


#mqtt functions (for reboot script)
def on_connect(client, userdata, flags, reason_code, properties):
    print(f"mqtt localhost connected with result code {reason_code}")
    client.subscribe("CMD/REACTIONWHEELS") #upstream being published to by LoRA_ULDL in the CommandHandler() function

def on_message(client, userdata, msg):
    reactionwheels_queue.put(msg.payload.decode()) #adds command string to queue, FIFO

ReactionWheels_client = mqtt.Client(mqtt.CallbackAPIVersion.VERSION2)
ReactionWheels_client.on_connect = on_connect
ReactionWheels_client.on_message = on_message
ReactionWheels_client.connect("localhost", 1883)
ReactionWheels_client.loop_start()

#GPIO initialization
motor_logic_switch = [GPIO.LOW,GPIO.LOW] #digital directionality pins, 1/0 and 0/1 for CW/CCW. These are pins 16, 18 in order
motor_logic_pins = [16, 18]
M1_pwm_pin = 29 #all physical board pins
M2_pwm_pin = 31
M3_pwm_pin = 37
pwm_Hz = 490 #matches arduino Uno test frequency
GPIO.setmode(GPIO.BOARD)
GPIO.setwarnings(False)

#motor logic setup
GPIO.setup(motor_logic_pins[0], GPIO.OUT, initial=GPIO.LOW)
GPIO.setup(motor_logic_pins[1], GPIO.OUT, initial=GPIO.LOW)
#motor pwm setup, start all at 0% pwm
GPIO.setup(M1_pwm_pin, GPIO.OUT)
GPIO.setup(M2_pwm_pin, GPIO.OUT)
GPIO.setup(M3_pwm_pin, GPIO.OUT)
M1_pwm = GPIO.PWM(M1_pwm_pin, pwm_Hz)
M2_pwm = GPIO.PWM(M2_pwm_pin, pwm_Hz)
M3_pwm = GPIO.PWM(M3_pwm_pin, pwm_Hz)
M1_pwm.start(0)
M2_pwm.start(0)
M3_pwm.start(0)
#initialize p1, p2, p3 values ahead of time for thoroughness (also for first command)
p1 = 0
p2 = 0
p3 = 0



try:
    while True:
        recieved_command = reactionwheels_queue.get()

        #first step is to parse the string, to determine both the direction of the wheels
        #and the values of each PWM to update string is of the below form:
        #"CMD:REACTIONWHEELS{INT,INT,INT}" where any of the ints can be signed either way
        match = re.fullmatch(r"CMD:REACTIONWHEELS\{(-?\d+),(-?\d+),(-?\d+)\}", recieved_command)
        if match:
            p1, p2, p3 = (int(g) for g in match.groups()) #pulls the ints out of the string, as ints

        #2 - determine if first int is negative (and change logic accordingly)
        if p1 < 0:
            motor_logic_switch = [GPIO.LOW, GPIO.HIGH]
        else:
            motor_logic_switch = [GPIO.HIGH, GPIO.LOW]
        #set logic/direction states
        GPIO.output(motor_logic_pins[0], motor_logic_switch[0])
        GPIO.output(motor_logic_pins[1], motor_logic_switch[1])

        #3 - update PWM values for each individual object, based on p1/p2/p3
        #safety check, if inputted pwm% (pn variable) is over 100, set to 0
        if abs(p1) > 100:
            p1 = 0
        if abs(p2) > 100:
            p2 = 0
        if abs(p3) > 100:
            p3 = 0
        #set pwm values
        M1_pwm.ChangeDutyCycle(abs(p1))
        M2_pwm.ChangeDutyCycle(abs(p2))
        M3_pwm.ChangeDutyCycle(abs(p3))
        

finally:
        print("Reaction Wheel motor control Script Deactivated")
        ReactionWheels_client.loop_stop()
        ReactionWheels_client.disconnect()
        M1_pwm.stop()
        M2_pwm.stop()
        M3_pwm.stop()
        GPIO.cleanup()

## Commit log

2026-07-13 added directories for the groundstation and flight computer software stack
2026-08-16 Added L293DNE Bridge & motor test file, successful results
2026-08-19 groundstation backend and frontend added
2026-08-25 vibe coded portions of frontend. WILL CHANGE TO MANUAL REACTION WHEEL CONTROL
2026-09-04 big changes to backend, flight computer ULDL, and groundstation arduino
2026-09-08 string parsing fixes for cubesat
    [GroundStation_Backend.py, LoRA_ULDL.py]
2026-09-09 claude bugfix for 2 packet problem
    [LoRA_ULDL.py]
2026-09-12 drunken garbage, likely wrong
    [Command_Handler.py, Mjolnir_Reboot.py]
2026-09-12 not so drunken idiocy (added reboot script, made passwordless)
    [Mjolnir_Reboot.py]
2026-09-16 final piping changes for IMU scripts, and reaction wheel scripts. ready to test
2026-09-18 fixed startracker executable line
    [Star_Tracker.py]
2026-09-18 changed external crystal line to fix garbage IMU readings
    [IMU.py]
2026-09-18 changed IMU delay to 1.5, weird temp readings
2026-09-22 final push, adding documentation files
    [18650_BMS_MkI.kicad_pcb, 18650_BMS_MkI.kicad_sch, BMS Tray.stl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]
